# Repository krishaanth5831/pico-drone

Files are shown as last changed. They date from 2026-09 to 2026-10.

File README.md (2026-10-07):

# pico-drone

A coreless quadcopter flight controller built on a **Raspberry Pi Pico 2 W**,
written in MicroPython.

Sensor drivers, control maths, and a component-by-component bench test suite —
with a hardware disarm line that a software bug cannot override.

> **Status: bench development.** This does not fly yet. There is no control link
> on the airframe, so `main.py` deliberately stops at sensor bring-up and never
> arms the motors. See [`docs/roadmap.md`](docs/roadmap.md).

> **Before running anything: `config.py`, `drivers/` and `flight/` must be
> copied onto the Pico's own filesystem first.** Opening a script in Thonny and
> pressing Run does not upload anything — without this step every script fails
> with `ImportError: no module named 'config'`. Run `./tools/upload.sh`, or see
> [step 2 below](#2-put-the-library-on-the-board) for the Thonny method.

## Hardware

| Part | Role |
|---|---|
| Raspberry Pi Pico 2 W | Flight controller (RP2350, dual-core 150 MHz) |
| 2× DRV8833 | Dual H-bridge motor drivers, two motors each |
| 4× coreless motors | Propulsion (8520 recommended — see [`docs/power.md`](docs/power.md)) |
| GY-521 (MPU6050) | 3-axis gyro + accelerometer |
| HMC5883L | 3-axis magnetometer, yaw reference |
| GY-GPS6MV2 (NEO-6M) | GPS position |
| 1S LiPo | Power |

Full wiring: [`docs/pinout.md`](docs/pinout.md).

## Layout

```
src/
  config.py            single source of truth for every pin and constant
  main.py              entry point - sensor bring-up, motors stay disarmed
  drivers/
    motors.py          DRV8833 bank with hardware arm/disarm
    heartbeat.py       onboard-LED liveness pulse, soft-timer driven
    mpu6050.py         GY-521 gyro + accelerometer
    hmc5883l.py        magnetometer, auto-detects the QMC5883L clone
    gps.py             NEO-6M NMEA parser
  flight/
    fusion.py          complementary filter -> roll and pitch
    pid.py             rate controller, anti-windup, no derivative kick
    mixer.py           X-quad motor mixing with desaturation

testing/               per-component bench procedures + scripts
docs/                  pinout, power/thrust/weight, roadmap
hardware/              KiCad schematic + wiring diagram
  frame/               3D-printed airframe: STLs + Onshape FeatureScript source
tests/                 CPython tests against a mocked hardware layer
tools/                 repo convention checks run in CI
```

## Getting started

### 1. Flash MicroPython

Grab the Pico 2 W UF2 from
[micropython.org](https://micropython.org/download/RPI_PICO2_W/), hold
**BOOTSEL** while plugging in, and copy the file to the `RP2350` drive that
appears. Full walkthrough in [`testing/01_pico_2w/`](testing/01_pico_2w/README.md).

### 2. Put the library on the board

The bench scripts import `config`, `drivers` and `flight`, and those imports
resolve against the **Pico's** filesystem — not your computer's:

```bash
pip install mpremote
./tools/upload.sh          # --list to check, --clean to wipe first
```

Or in Thonny: `View → Files`, select `config.py`, `drivers` and `flight`,
right-click → **Upload to /**. Re-upload after any change under `src/`.

`main.py` is deliberately excluded. MicroPython auto-runs it on every boot *and
every soft-reboot* — which is what Thonny's Run button always does first — so a
`main.py` on the board hijacks every test run before your script executes. If
you see the shell print `MPY: soft reboot` repeatedly with none of your test's
own output, this is why: run `./tools/upload.sh` again, which removes it.

### 3. Work through the bench tests

Do these **in order** — each assumes the previous one passes.

| # | Component | Motors spin? |
|---|---|---|
| [01](testing/01_pico_2w/README.md) | Pico 2 W bring-up | no |
| [02](testing/02_drv8833/README.md) | DRV8833 driver, no motor attached | no |
| [03](testing/03_coreless_motor/README.md) | Motor mapping and direction | **yes** |
| [04](testing/04_gy521_imu/README.md) | IMU | no |
| [05](testing/05_hmc5883l_compass/README.md) | Compass | no |
| [06](testing/06_gy_gps6mv2/README.md) | GPS | no |
| [07](testing/07_lipo_power/README.md) | Power system, brownout hunt | **yes** |

Index and safety notes: [`testing/README.md`](testing/README.md).

### 4. Run it

**Do this separately from the bench tests above, and remove it again afterwards.**
`main.py` auto-runs on every boot and soft-reboot, so leaving it on the board
hijacks every test run in step 3 - if you go back to bench testing after this,
delete it first (`./tools/upload.sh` does this for you automatically).

```bash
mpremote fs cp src/main.py :
```

Then reset the board. You get live attitude, heading and GPS status streamed to
the REPL, with the motors held hardware-disarmed throughout.

## Safety model

**`GP15` (physical pin 20) drives `SLP` on both DRV8833s.** Held low, the driver
outputs go high-impedance and the motors are dead no matter what the PWM
registers contain. This is a hardware disarm, not a software convention.

Enforced throughout:

- `MotorBank` drives `SLP` low **before** any PWM channel is constructed, so no
  stale duty can reach a motor during startup.
- Using it as a context manager disarms on every exit path, exceptions included.
- Keep that pattern in any new motor-driving code: a `finally` block or
  `with MotorBank()`, no exceptions.
- `MAX_DUTY` is capped at 0.70 — two DRV8833s thermally shut down at sustained
  full throttle — and `tests/test_config.py` fails if it is raised.
- Nothing in this repo arms motors at power-on.

**Every bench procedure assumes props are off.**

### LED heartbeat

Every script pulses the onboard LED for as long as it runs — a long on, short off
that reads as a glow. Pulsing means the board is powered and its scheduler is
running; **stopping and restarting means it reset**, which on this airframe means
a brownout. It runs on a soft timer, so it survives blocking calls, and
Keep that pattern in anything new: start it, stop it, no orphaned timers.

It does not prove the main loop is progressing — a soft timer keeps firing even
if the code above it hangs. It catches reset and power loss, which is the failure
this hardware actually has.

## Firmware

[`firmware/`](firmware/README.md) is the integrated flight controller — sensor
fusion, cascaded PID, motor mixing, and the arm/disarm safety logic, built on
the drivers and control maths in `src/`. It self-levels and holds a heading; it
does not hold altitude or position, since nothing on this airframe measures
either. Read `firmware/README.md` in full before running it — it explains the
safety model and the manual tuning procedure, both of which matter more than
usual given there is still no control link or physical kill switch.

## Development

```bash
python3 -m venv .venv
./.venv/bin/pip install pytest ruff

./.venv/bin/python -m pytest        # 80 tests, no hardware needed
./.venv/bin/ruff check .
```

`tests/mocks/machine.py` fakes MicroPython's hardware layer — `Pin` records its
levels, `PWM` its duty, `I2C` serves bytes from a register dict — so the same
code the board runs can be exercised on a computer with no board attached.

> On a machine with ROS installed, prefix pytest with
> `env -u PYTHONPATH PYTEST_DISABLE_PLUGIN_AUTOLOAD=1` — ROS's `launch_testing`
> plugin auto-loads and crashes.

## License

[MIT](LICENSE)

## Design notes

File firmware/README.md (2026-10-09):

# Firmware — attitude-hold flight controller

This is the integrated flight code: sensor fusion, cascaded rate/angle PID
loops, motor mixing, and the safety logic that arms and disarms the motors.
It builds entirely on the drivers and control maths already validated in
`src/` and `testing/` — nothing here is new hardware code, only the loop that
ties it together.

## Wiring — every component, in one place

This mirrors [`docs/pinout.md`](../docs/pinout.md) and the per-component
tables in `testing/`, gathered here so the full airframe wiring is on one
page once you're past bench-testing individual parts and wiring the real
thing. `src/config.py` is the authoritative source if this ever drifts from
it — pins are imported from there, never hardcoded.

Hold the Pico 2 W with the **USB port at the top**. Pin 1 is the top-left
pad; numbers run down the left side (1–20), then continue up the right side
(21–40).

### Pico 2 W — onboard LED

| Signal | Pico 2 W | Physical pin | Note |
|---|---|---|---|
| Onboard LED | `Pin("LED")` | — | Behind the CYW43 WiFi chip on "W" boards — on/off only, cannot be PWM'd |

`GP23`, `GP24`, `GP25`, `GP29` are wired to the CYW43 WiFi/Bluetooth chip and
are **reserved** — never assign these. They are internal only; physical pins
29, 31, 32 and 34 are GP22, GP26, GP27 and GP28.

### DRV8833 #1 (motors 1 and 2)

| DRV8833 pin | Pico 2 W | Physical pin | Note |
|---|---|---|---|
| `VM` / `VCC` / `VMOT` | Bench: HW-131 5 V rail. Airframe: battery + direct | — | Never from the Pico |
| `GND` | Bench: HW-131 GND rail. Airframe: battery star point | — | Motor current returns here, not through the Pico |
| `SLP` / `nSLEEP` / `EEP` | GP15 | 20 | Shared with DRV #2 — hardware arm/disarm for all four motors |
| `AIN1` | GP10 | 14 | Motor 1 PWM |
| `AIN2` | GND | — | Tie low — channel A unidirectional |
| `BIN1` | GP11 | 15 | Motor 2 PWM |
| `BIN2` | GND | — | Tie low — channel B unidirectional |
| `nFAULT` *(if present)* | GP14 | 19 | Shared with DRV #2, open-drain, low = fault |
| `AOUT1`/`AOUT2` | Motor 1 leads | — | Polarity picks spin direction, not software |
| `BOUT1`/`BOUT2` | Motor 2 leads | — | Polarity picks spin direction, not software |

### DRV8833 #2 (motors 3 and 4)

Identical to #1, sharing the same `SLP`, `VM`, and `GND`:

| DRV8833 pin | Pico 2 W | Physical pin | Note |
|---|---|---|---|
| `VM` | Same as DRV #1 | — | |
| `GND` | Same as DRV #1 | — | |
| `SLP` | GP15 | 20 | Same net as DRV #1 |
| `AIN1` | GP12 | 16 | Motor 3 PWM |
| `AIN2` | GND | — | Tie low |
| `BIN1` | GP13 | 17 | Motor 4 PWM |
| `BIN2` | GND | — | Tie low |
| `nFAULT` | GP14 | 19 | Same net as DRV #1 |
| `AOUT1`/`AOUT2` | Motor 3 leads | — | |
| `BOUT1`/`BOUT2` | Motor 4 leads | — | |

### Motors — airframe positions

Standard X quad, viewed from above, nose up the page. Diagonal pairs share a
rotation direction so their yaw torques cancel in the hover.

```
      M3 (CW)          M1 (CCW)
        \                 /
         \   +--------+  /
          +--|  PICO  |-+
             |   IMU  |
          +--|        |-+
         /   +--------+  \
        /                 \
      M2 (CCW)          M4 (CW)
```

| Motor | Position | Rotation | Driver channel | PWM pin |
|---|---|---|---|---|
| M1 | front-right | CCW | DRV #1 ch A | GP10 |
| M2 | rear-left | CCW | DRV #1 ch B | GP11 |
| M3 | front-left | CW | DRV #2 ch A | GP12 |
| M4 | rear-right | CW | DRV #2 ch B | GP13 |

### GY-521 (MPU6050) — IMU, on I2C0

| GY-521 pin | Pico 2 W | Physical pin | Note |
|---|---|---|---|
| `VCC` | 3V3(OUT) | 36 | |
| `GND` | GND | 38 | |
| `SDA` | GP4 | 6 | I2C0 data, the only device on the bus |
| `SCL` | GP5 | 7 | I2C0 clock |
| `XDA`, `XCL`, `ADO`, `INT` | — | — | Leave unconnected (`ADO` floating = address `0x68`) |

Mount as close to the airframe's centre of mass as possible, and decouple
from vibration (foam tape) — bolted rigidly to the frame, prop vibration
feeds straight into the accelerometer and corrupts the attitude estimate.

### HMC5883L — compass: removed from the build

Taken out on 2026-10-09. With it attached the IMU dropped off I2C whenever the
motors ran — most likely the breadboard-rail grounding fault later found with
the GPS (see the grounding rule above), not the compass itself. It stays out:
nothing needs a heading yet, and a few cm from four motors its readings are
swamped anyway. `flight_controller.py` detects that it is missing and holds
yaw by the gyro rate loop alone, so the heading drifts slowly. See
[`testing/05_hmc5883l_compass/`](../testing/05_hmc5883l_compass/README.md) if
it comes back.

### GY-GPS6MV2 (NEO-6M) — GPS, on UART0

| GY-GPS6MV2 pin | Pico 2 W | Physical pin | Note |
|---|---|---|---|
| `VCC` | Bench: VBUS. Battery: 3V3(OUT) | 40 / 36 | VBUS is 5 V from USB into the module's own regulator — it gets a lock there and stays off the IMU's 3.3 V line |
| `GND` | GND | 3 | Directly below GP0/GP1, keeps the wire short |
| `TX` | GP1 = UART0 RX | 2 | **Crossover** — GPS transmit to Pico receive |
| `RX` | GP0 = UART0 TX | 1 | **Crossover**, only needed to reconfigure the module |

Check the board's silkscreen before wiring — these ship in `VCC RX TX GND`
and `GND TX RX VCC` header orders depending on the batch; the label is
authoritative, not the pin position. Mount with the ceramic antenna facing
up, clear view of sky, away from motors and power wiring.

### Power — bench (current setup, props off)

No battery yet. The Pico runs from the laptop's USB; the motors from an HW-131
breadboard power supply. Details and limits in
[`docs/power.md`](../docs/power.md#bench-power-hw-131-breadboard-supply).

```
USB charger (>=2 A) -> HW-131 --> rail A, jumper 5 V --> DRV #1 VM, DRV #2 VM
                              --> rail B, jumper OFF
                              --> GND rail <--+-- DRV #1 GND, DRV #2 GND
                                              +-- ONE wire to Pico GND

Laptop USB -> Pico 2 W --> 3V3 OUT (pin 36) --> GY-521 VCC
                       --> VBUS    (pin 40) --> GPS VCC
                       --> GND (38) -> GY-521 GND,  GND (3) -> GPS GND
```

**Grounding rule:** once the HW-131 is plugged in, the breadboard's power rails
are motor ground. Sensor grounds go straight to Pico GND pins (GY-521 → 38,
GPS → 3), never to a rail; exactly one wire joins Pico GND to the HW-131 GND
rail; the HW-131 runs off a wall charger, not the laptop. Break this and the IMU
drops off I2C the moment the motors spin. Full explanation and a multimeter
check in [`docs/power.md`](../docs/power.md#grounding-rule--breadboard-rails-are-motor-ground).

### Power — airframe (battery)

```
1S LiPo (+) --+-------------------> DRV #1 VM --+-- 470uF -- GND
              |                                  |
              +-------------------> DRV #2 VM --+-- 470uF -- GND
              |
              +--[ SS14 Schottky ]-> Pico VSYS (physical pin 39)

1S LiPo (-) ---- star point ----+--> DRV #1 GND
                                +--> DRV #2 GND
                                +--> Pico GND (physical pin 38)
```

| Connection | Pico 2 W | Physical pin | Note |
|---|---|---|---|
| Battery + via Schottky | VSYS | 39 | VSYS accepts 1.8–5.5 V |
| Battery − (star ground) | GND | 38 | |
| Battery + direct | — | — | To both DRV8833 `VM` pins, not to the Pico |
| *(bench only)* USB 5 V | VBUS | 40 | Alternative driver supply for bench work |

**Never connect battery + to 3V3 (pin 36)** — that regulator only supplies
~300 mA, nowhere near enough for a motor.

The 470 µF capacitors sit right at each driver's `VM`/`GND` pins as a local
energy reservoir — the battery chemistry can't respond to a millisecond
current spike, the capacitor can. The Schottky diode on VSYS stops a motor's
current surge from browning out the Pico through the shared battery rail.

### I2C addresses (I2C0, GP4/GP5)

| Device | Address |
|---|---|
| MPU6050 / GY-521 | `0x68` (`0x69` with `ADO` high) — the only device on the bus |

### Full wiring diagrams and mounting detail

Each `testing/0X_*/README.md` covers its component in more depth — soldering
gotchas, why AIN2/BIN2 are tied low, why the GPS crossover trips people up,
what a `nFAULT` low actually means. Work through those in order
(`testing/README.md` is the index) before wiring the full airframe from this
page.

## Read this before you run anything

**This is attitude stabilization, not hover.** It self-levels roll and pitch
and holds a heading, at whatever throttle `tuning.py` sets. It cannot hold
altitude or position, because nothing on this airframe measures either:

- The GPS updates at 1–5 Hz with 1–10 m accuracy — useless for noticing a 10 cm
  drop, let alone correcting one before it matters.
- There is no barometer, no sonar, no optical flow. Nothing on this bench
  measures height at all.

So this will climb, sink, and drift with wind, battery voltage sag, and
airframe asymmetry, even while perfectly level. True hover — holding a fixed
height — needs a barometer at minimum (a BMP280 is a couple of dollars and a
4-wire I2C add-on); this code leaves a clean seam for one but does not fake
having it.

**There is no control link and no physical kill switch.** The only way to stop
a misbehaving motor right now is pulling the battery. Every safety mechanism
below is a software approximation of what a real RC failsafe would do — treat
them as backups, not as a substitute for standing next to the battery
connector with your hand on it.

## Safety model

| Layer | What it does |
|---|---|
| `MotorBank()` construction | Drives `SLP` low before anything else runs — motors are hardware-disarmed the instant the script starts |
| `tuning.LIVE_MOTORS = False` (default) | The entire control loop runs and prints what it *would* do; `arm()` is never called, so nothing can spin regardless of any bug below this line |
| "Type ARM" prompt | Only reached if `LIVE_MOTORS` is `True`. Blocks until answered — no REPL attached means it blocks forever, which is the correct failure mode |
| `TILT_LIMIT_DEG` | Auto-disarms if roll or pitch exceeds this — catches a flip or a bad gain before it grinds into whatever it's mounted on |
| `RUN_SECONDS` | Auto-disarms after a fixed time no matter what — there is no way to command a stop mid-run otherwise |
| `try`/`finally` around the whole loop | Disarms on Ctrl-C, on any exception, and on the abort path — every exit disarms |

That confirmation prompt is a manual `MotorBank()` construction, not
`with MotorBank() as bank:` — the context manager's `__enter__` calls `arm()`
unconditionally, which would have spun the motors *before* the prompt was even
answered. That was a real bug caught by testing the abort path, not by reading
the code — worth remembering if you extend this file.

## Files

| File | Purpose |
|---|---|
| `flight_controller.py` | The control loop. Open it directly in Thonny and run it, same as anything in `testing/` |
| `tuning.py` | Every gain, limit, and the `LIVE_MOTORS` switch — the only file you should need to edit while tuning |
| `lift.py` | Standalone lift test: staggered spin-up, ramp, hold until Stop, with self-levelling (`LEVELLING`, level taken from how it sits at start) or bench mode (all motors equal). Gains and the `WIRING` mode live inline at the top, so Thonny edits take effect without re-uploading |
| `imu_motor_check.py` | Runs each motor on its own while hammering the IMU and counts failed reads — finds which motor (or which power/ground path) knocks the IMU off the bus |

## Setup

1. Complete `testing/01` through `testing/07` first — this assumes every
   component already works individually.
2. Run `testing/05_hmc5883l_compass/` **with the airframe fully assembled**
   and copy the printed `offset`/`scale` into `tuning.py`'s `MAG_OFFSET` /
   `MAG_SCALE`. Skipping this leaves heading-hold steering off whatever
   distortion happens to be nearby.
3. Upload the library, which now includes `tuning.py`:
   ```bash
   ./tools/upload.sh
   ```
4. Open `firmware/flight_controller.py` in Thonny and run it. `LIVE_MOTORS` is
   `False` by default — nothing can spin yet.

## Tuning procedure

Full detail and rationale is in the comments at the top of `tuning.py` — this
is the short version:

1. **Dry run, props off.** Tilt the board by hand and watch the printed mixer
   output. Confirm the *sign* of every axis before anything else: tilt right,
   the roll term should push right-side motors down and left-side up. Get a
   sign wrong here and the first live attempt flips immediately.
2. **Props on, in a restraining rig** that physically cannot leave the ground
   even at full deflection. Set `LIVE_MOTORS = True`, keep `RUN_SECONDS` short.
3. **Rate loop first**, angle gains still at zero. Raise `*_RATE_KP` from zero
   until a hand disturbance makes it oscillate at a fixed frequency, back off
   to roughly half that, then add a little `*_RATE_KD` to damp the wobble.
4. **Angle loop second**, once the rate loop is solid. Small `*_ANGLE_KP`,
   raised until it holds level without overshoot.
5. **Yaw/heading last**, using `HEADING_KP`.

If anything oscillates violently or looks like it's about to flip: set
`LIVE_MOTORS = False` and pull the battery. That's not a tuning problem to
push through — it's the signal to lower gains and re-check the rig.

## Why not autotune, why not RL

**Relay-based autotune** (forcing an oscillation and computing gains from its
period and amplitude — what Betaflight/ArduPilot's "autotune" features do
under the hood) is a legitimate, ML-free technique that could run entirely on
the Pico. It isn't built into this first version because it drives the motors
autonomously to find the oscillation, and this bench has no kill switch faster
than the battery connector. Worth adding once a physical kill switch or a real
control link exists — see `docs/roadmap.md`.

**On-device reinforcement learning** was ruled out outright. Training a
continuous-control policy from scratch typically needs 10⁴–10⁷ real
interactions; MicroPython has no autodiff and the stock firmware has no
`numpy`-equivalent (`ulab` isn't bundled by default); and every failed
training rollout on a real spinning-prop airframe is a potential crash.
Training in simulation and deploying a small pretrained policy for inference
only ("sim-to-real") is possible in principle, but needs an accurate physics
model and system identification of this specific airframe first — a
substantial project on its own, and PID will be flying reliably long before
that pipeline would even be validated.

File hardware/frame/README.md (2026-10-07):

# Frame — 3D-printed airframe

A one-piece printed quad frame sized around this build's parts, a bolt-on
GPS + compass mast, and a small tolerance coupon to print first.

| File | Part | Mass (PLA) |
|---|---|---|
| `pico_drone_frame.stl` | Frame: deck, arms, motor pods, battery bay | 8.7 g |
| `pico_drone_gps_mast.stl` | GPS + compass mast (bolts on, optional) | 2.7 g |
| `pico_drone_tolerance_coupon.stl` | Fit test: motor bores + header slots | — |
| `pico_drone_frame.fs` | Onshape FeatureScript source that generates all three | — |

The model is fully parametric in Onshape (document **Pico Drone Frame**,
private: <https://cad.onshape.com/documents/835a5cba0ddda1a520f81383>).
Double-click the *Pico Drone Frame* feature to change any dimension or
clearance, and everything regenerates. To reproduce it in another document,
paste `pico_drone_frame.fs` into a new Feature Studio and add the feature to a
Part Studio.

> **Thrust check before you print.** With the 720 motors, `docs/power.md`
> puts usable thrust at about 61 g. The fit-check model weighs the full build
> at **65.7 g without wires** (with GPS), so it will not lift. 8520 motors
> (~119 g usable) give about 1.5:1 with the GPS fitted. To refit the pods,
> set *Motor diameter* to 8.5 and re-export — the 55 mm props and every other
> dimension stay the same.

## Print

The STLs are already in print orientation: flat deck face (or platform face)
on the bed. **No supports.** Every overhang is a bridge or a 45° slope.

- PLA, 0.4 mm nozzle, 0.2 mm layers, 3 walls, any infill. Most walls are
  1.0–1.6 mm thick, so they print solid.
- Every corner is rounded and every edge has a 0.4 mm fillet (the 8 bottom
  edges of the arm webs take a smaller one), so there are no sharp edges.
  The only unrounded edges are inside the shallow 0.4 mm engraved labels.
- **Print the coupon first** (about 10 minutes):
  - **Motor rings:** 5 rings with bore allowances −0.1 / 0.0 / +0.1 /
    +0.2 / +0.3 mm, marked by 1–5 dots. Pick the ring that grips a motor
    firmly without forcing it. If that isn't the +0.1 ring (3 dots), set
    *Motor bore allowance* to its value and re-export.
  - **Header slots:** 3 slots of 3.0 / 3.4 / 3.8 mm. A 2.54 mm header strip
    should drop into the 3.4 slot freely. If it doesn't, change *Header slot
    width*.

## Layout

Nose is +X. Motor labels are engraved on the arms, and arrows on the front
two arms point forward. Rotation directions match `firmware/README.md`:

```
                  nose
      M3 (CW)              M1 (CCW)
         \                   /
          \ +--------+------+
            |        | DRV1 |
            |  Pico  |------|
            |  2 W   | IMU  |
            |        |------|
            |  USB   | DRV2 |
          / +--------+------+ \
         /     battery under    \
      M2 (CCW)              M4 (CW)
```

- The **Pico** sits in the left column with its USB port at the rear, where a
  notch in the deck leaves room for the cable. The antenna end faces the
  front edge, partly over a window in the deck.
- The **GY-521** sits in the middle of the right column, as close to the centre
  of mass as the layout allows (computed CG offset 1.5 mm, -0.2 mm). Turn it
  so the silkscreen **X arrow points to the nose**. That edge has slots on
  both sides, so either 180° orientation fits. If your board's X arrow runs
  along the short edge, tick *GY-521 silkscreen X runs along the short edge*.
- The **battery** (EEMB 852040, 20 × 40 × 8.5 mm) slides into the bay under
  the deck from the rear. It stops against the front wall and is held down by
  two 45° rails. Put a zip tie or rubber band through the rear truss windows
  so it can't slide out.

## Fitting the boards (headers stay on, pins down)

Each board's header plastic drops through a slot, so the PCB lies flat on the
deck. Its pins hang into a 10 mm wiring bay above the battery. Solder wires to
the pin tips. Dupont housings need about 18 mm: set *Wiring gap under deck* to
18 if you use them.

| Board | Held by |
|---|---|
| Pico 2 W, DRV8833 ×2 | header strips in the slots + thin double-sided tape |
| GY-521 | 1 mm foam tape (vibration isolation, per `testing/04_gy521_imu`) |
| GY-GPS6MV2 + antenna, GY-271 | foam tape on the mast platform; antenna taped on top of the NEO-6M module. Turn the GY-271 so its silkscreen X arrow points to the nose (either 180° orientation fits), and recalibrate it once it's on the airframe |
| Mast | leg tabs drop through the deck slots, 2× M2 × 6 self-tapping screws from the front and rear |
| Motors | split clamp with a 45° bottom lip; leads exit through the bottom hole |

Motor leads run along the arm webs; the two holes in each web take a zip tie.

## Tolerances

| Fit | Clearance |
|---|---|
| Board pockets | 0.3 mm per side |
| Header strip in slot (Pico, IMU, GY-271, GPS) | 3.4 mm slot for a 2.54 mm strip, 0.43 mm per side |
| DRV8833 header slots | 3.8 mm (row spacing on clone boards varies) |
| Motor bore | Ø motor + 0.1 mm with a 0.8 mm split, so the clamp grips |
| Battery bay | 0.4 mm per side |
| Mast tab in deck slot | 0.15 mm per side |

These were checked in Onshape against fit-check dummies of every part.
Minimum clearances: 0.05 mm board-to-deck (the dummies float by design),
0.26 mm at the header strip corners, 0.2 mm battery, 0.43 mm GPS header, and
more than 1 mm between the props and anything else.

## Dimensions used

- **Pico 2 W**: official datasheet. 51 × 21 × 1 mm, header rows 17.78 mm
  apart, 1.3 mm USB overhang, 14 × 9 mm antenna keep-out.
- **Clone boards**: typical published sizes. **Caliper yours** and edit the
  dialog before printing; sellers differ by 1–2 mm.

| Board | Size used |
|---|---|
| GY-521 | 21.2 × 16.4 mm |
| DRV8833 (red EEP/ULT module) | 18.5 × 16 mm |
| GY-271 | 14.8 × 13.5 mm |
| GY-GPS6MV2 | 36 × 25 mm; antenna 25 × 25 × 6.2 mm |
| 852040 battery | 42 × 20 × 8.5 mm (2 mm allowance for the protection PCB) |
| 720 motor, 55 mm props | Ø7 × 20 mm |

## Re-exporting after a change

Onshape exports in flight orientation. Either flip the part 180° about X in
the slicer, or use *lay flat* on the large deck face.

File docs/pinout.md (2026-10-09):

# Consolidated pin map

Every GPIO on the airframe, in one place. The authoritative source is
[`src/config.py`](../src/config.py) — this document mirrors it, and
Keep it that way when editing `testing/` scripts - import pins from `config.py`
rather than hardcoding a GPIO number.

## Board orientation

Hold the Pico 2 W with the **USB port at the top**. Pin 1 is the top-left pad;
numbers run down the left side (1–20), then continue up the right side (21–40).

## Signals

| Function | Device pin | Pico GPIO | Physical pin |
|---|---|---|---|
| Motor 1 PWM | DRV #1 `AIN1` | GP10 | 14 |
| Motor 2 PWM | DRV #1 `BIN1` | GP11 | 15 |
| Motor 3 PWM | DRV #2 `AIN1` | GP12 | 16 |
| Motor 4 PWM | DRV #2 `BIN1` | GP13 | 17 |
| Motor arm / kill | both DRV `SLP` | GP15 | 20 |
| Driver fault *(optional)* | both DRV `nFAULT` | GP14 | 19 |
| IMU data | GY-521 `SDA` | GP4 | 6 |
| IMU clock | GY-521 `SCL` | GP5 | 7 |
| GPS → Pico | GY-GPS6MV2 `TX` | GP1 | 2 |
| Pico → GPS | GY-GPS6MV2 `RX` | GP0 | 1 |
| — | DRV `AIN2`/`BIN2` ×4 | **tie to GND** | 3, 8, 13, 18, 23, 28, 33, 38 |

The HMC5883L compass was **removed from the build on 2026-10-09**. With it
attached the IMU dropped off I2C whenever the motors ran — most likely the same
breadboard-rail grounding fault later found with the GPS, not the compass itself.
It stays out anyway: the build doesn't need a heading yet, and a few cm from the
motors its readings are swamped. The GY-521 alone gives roll, pitch and
yaw rate; `firmware/flight_controller.py` runs without a compass (yaw rate-hold,
heading drifts slowly). Its component test in `testing/05_hmc5883l_compass/` is
kept in case it comes back on a mast.

## Power rails — bench (current setup, props off)

No battery. The Pico runs from the laptop's USB and the motors from an HW-131
(MB102-style) breadboard power supply. Full picture in
[`power.md`](power.md#bench-power-hw-131-breadboard-supply).

| Rail | Feeds | Physical pin |
|---|---|---|
| Laptop USB → Pico | the Pico itself | — |
| 3V3(OUT) | GY-521 `VCC` only | 36 |
| VBUS (5 V from USB) | GPS `VCC` (the module has its own 3.3 V regulator) | 40 |
| HW-131 rail, jumper on **5 V** | DRV #1 `VM`, DRV #2 `VM` — nothing else | — |
| HW-131 GND rail | DRV #1 `GND`, DRV #2 `GND`, one wire to Pico GND | — |
| Pico GND | GY-521 `GND` (38), GPS `GND` (3), the one wire to the HW-131 GND rail | 3, 38 |

**The breadboard's power rails are motor ground once the HW-131 is plugged in.**
Sensor grounds go straight to Pico GND pins (GY-521 → 38, GPS → 3), never to a
rail, and exactly one wire joins Pico GND to the HW-131 GND rail. Getting this
wrong knocks the IMU off I2C the moment the motors spin — see the
[grounding rule](power.md#grounding-rule--breadboard-rails-are-motor-ground).
HW-131 5 V never goes to VSYS or VBUS.

## Power rails — airframe (battery, planned)

| Rail | Feeds | Physical pin |
|---|---|---|
| 3V3(OUT) | GY-521 `VCC`, GPS `VCC` | 36 |
| VSYS ← battery via Schottky | the Pico itself | 39 |
| Battery + direct | DRV #1 `VM`, DRV #2 `VM` | — |
| GND | everything, star-grounded at the battery | 38 (also 3, 8, 13, 18, 23, 28, 33) |

## Reserved — never assign these

| GPIO | Physical pin | Used by |
|---|---|---|
| GP23 | none (internal) | CYW43 WiFi power-save |
| GP24 | none (internal) | CYW43 data |
| GP25 | none (internal) | CYW43 chip select |
| GP29 | none (internal) | CYW43 clock / VSYS sense |

These four are not broken out to the header at all. Physical pins 29, 31, 32 and
34 are GP22, GP26, GP27 and GP28, which are ordinary free GPIO.

On Pico W and Pico 2 W these are wired to the WiFi/Bluetooth chip and are not
free GPIO. That is also why the onboard LED is `Pin("LED")` rather than `Pin(25)`
and cannot be PWM'd. `tests/test_config.py` fails if any of them is assigned.

## I2C addresses

| Device | Address |
|---|---|
| MPU6050 / GY-521 | `0x68` (`0x69` with `ADO` high) |

The IMU is alone on I2C0 (GP4/GP5). A scan should return `[104]`.

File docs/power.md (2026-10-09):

# Power, thrust and weight

The three numbers that decide whether this build flies.

## Bench power (HW-131 breadboard supply)

The current setup, props off, no battery. The Pico runs from the laptop's USB
(Thonny needs it anyway); the motors run from an HW-131 (MB102-style)
breadboard supply plugged into the breadboard's rails.

```
USB charger (>=2 A) -> HW-131 --> rail A, jumper 5 V --> DRV #1 VM, DRV #2 VM
                              --> rail B, jumper OFF
                              --> GND rail <--+-- DRV #1 GND, DRV #2 GND
                                              +-- ONE wire to Pico GND

Laptop USB -> Pico 2 W --> 3V3 OUT (pin 36) --> GY-521 VCC
                       --> VBUS    (pin 40) --> GPS VCC
```

- **Feed the HW-131 from a USB charger, not the barrel jack.** On the barrel
  jack its 5 V comes through an AMS1117 that gives up around 0.7 A. On most
  boards the USB input bypasses that regulator, so the charger sets the limit.
  Not the laptop: it is already feeding the Pico.
- **The sensors stay on the Pico.** Off the HW-131 they would see every motor
  sag, and switching one supply off while the other is on back-powers through
  the I2C lines.
- **Grounding — read the rule below.** Getting it wrong takes the IMU off the
  bus as soon as the motors spin.
- **5 V on the motors is fine with props off.** `MAX_DUTY` 0.70 averages
  ~3.5 V, right at the coreless 3.7 V rating. Never raise `MAX_DUTY` on 5 V.
- **The breadboard rails carry ~1 A per contact.** Keep both DRVs close to the
  HW-131 and check for a split in the middle of long rails.
- **Kill switch:** the HW-131's power button cuts the motors instantly.
- Power-up: HW-131 on, then Pico USB. Power-down: Stop in Thonny, then HW-131 off.

### Grounding rule — breadboard rails are motor ground

**The HW-131 plugs into the breadboard's long power rails, so every one of those
rails is motor ground (and motor power).** Nothing on the sensor side may touch
them:

- **GY-521 `GND` → Pico pin 38, GPS `GND` → Pico pin 3** — straight to the Pico,
  each on its own wire. Never to a breadboard rail.
- **Exactly one wire** joins a Pico GND pin to the HW-131 GND rail. That is the
  only place the two grounds meet.
- **Feed the HW-131 from a wall charger, not a second laptop USB port.** With
  both the Pico and the HW-131 on the laptop, motor current gets a second path
  home through the laptop and the Pico's ground.
- Keep sensor wires (SDA/SCL, GPS TX/RX) away from motor leads.

**The symptom when this is wrong:** the IMU reads fine with the motors off, then
the moment they spin `lift.py` stops with `IMU stopped answering (31 failed
reads in a row)` — every read fails, not just some. The IMU alone often survives;
adding any second module (GPS, compass) wired to a rail tips it over. Seen and
fixed on 2026-10-09: moving the GPS ground off the rail onto Pico pin 3 cured it.

**Check with a multimeter:** with the motors running (`LEVELLING = False` in
`lift.py` so it keeps going), DC millivolts between Pico pin 38 and the GY-521
`GND` pin should read ~0. Tens of mV means motor current is flowing through the
sensor ground.

## Power topology (airframe, battery)

Motor current and Pico current take separate paths from the battery, meeting only
at the terminals:

```
1S LiPo (+) --+-------------------> DRV #1 VM --+-- 470uF -- GND
              |                                  |
              +-------------------> DRV #2 VM --+-- 470uF -- GND
              |
              +--[ SS14 Schottky ]-> Pico VSYS (pin 39)

1S LiPo (-) ---- star point ----+--> DRV #1 GND
                                +--> DRV #2 GND
                                +--> Pico GND (pin 38)
```

**Capacitors** absorb the millisecond current spikes the battery's chemistry
cannot. Mount them physically close to each driver's VM/GND pins.

**The Schottky** prevents USB 5 V backfeeding the LiPo when both are connected.
Without it, connect only one at a time.

**Star grounding** keeps motor return current out of the Pico's ground wire,
where it would create offset voltages that read as IMU noise.

Full brownout explanation and the test procedure:
[`testing/07_lipo_power/`](../testing/07_lipo_power/README.md).

## Driver losses

Each DRV8833 half-bridge pair has ~360 mΩ of on-resistance. At 1.5 A that drops
~0.54 V and dissipates ~0.8 W **per motor**.

| Setup | R path | Drop @1.5 A | Heat per chip | Motor sees | Thrust (8520) |
|---|---|---|---|---|---|
| **2 chips, 2 motors each** *(current build)* | 360 mΩ | 0.54 V | **1.6 W** | 3.06 V | ~101 g |
| 4 chips, 1 motor, not paralleled | 360 mΩ | 0.54 V | 0.81 W | 3.06 V | ~101 g |
| 4 chips, 1 motor, channels paralleled | 180 mΩ | 0.27 V | 0.41 W | 3.33 V | ~120 g |
| 4× SI2302 MOSFET | 50 mΩ | 0.08 V | negligible | 3.52 V | ~134 g |

*(1S pack sagging to ~3.6 V under load; coreless thrust scales roughly with V².)*

### The current build's limitation

Two chips means two motors per package at ~1.6 W. The cheap breakouts have no
heatsinking, so **sustained full throttle reaches the 150 °C thermal shutdown**
and cuts both that chip's motors without warning.

`MAX_DUTY` is capped at **0.70** in [`src/config.py`](../src/config.py) for this
reason, and `tests/test_config.py` fails if it is raised.

### Upgrade paths

**Four DRV8833s with channels paralleled** — tie `AIN1`↔`BIN1`, `AIN2`↔`BIN2`,
`AOUT1`↔`BOUT1`, `AOUT2`↔`BOUT2` on each chip, one chip per motor. Halves both
the voltage drop and the heat. Costs ~5 g, returns ~19 g of thrust. Only parallel
*within* one chip — two chips will not switch in sync.

**Four SI2302 MOSFETs** — drone props never reverse, so an H-bridge is not
needed. Recovers nearly all the loss, weighs ~1 g total, costs pennies. This is
what commercial coreless drones use.

## Weight budget

| Item | Weight |
|---|---|
| Pico 2 W (with headers) | ~10 g |
| 2× DRV8833 breakouts | ~5 g |
| GY-521 (HMC5883L removed 2026-10-09) | ~2 g |
| GY-GPS6MV2 | ~14 g |
| 1S 600 mAh LiPo | ~15 g |
| 4 motors + props | ~22 g |
| Frame, wire, connectors | ~25 g |
| **Total with GPS** | **~94 g** |
| **Total without GPS** | **~80 g** |

## Thrust-to-weight

You want **2:1 minimum** for controllable flight. Below ~1.5:1 the aircraft
cannot accelerate upward fast enough to correct a disturbance — it wallows and
eventually falls out of the sky regardless of PID tuning.

| Motor | Thrust each | Total | After driver loss | T:W with GPS | T:W without |
|---|---|---|---|---|---|
| 720 (7 mm) | ~18 g | 72 g | ~61 g | 0.65 — will not lift | 0.76 — will not lift |
| 8520 (8.5 mm) | ~35 g | 140 g | ~119 g | 1.27 — marginal | **1.49 — flyable** |

**Build v1 without the GPS.** It is 15% of all-up weight, and it is useless until
the stabilisation loop works anyway. It bolts on later in minutes.

With 8520 motors and no GPS you are at roughly 1.5:1 — enough to develop and tune
the control loop. Swapping to MOSFETs later takes it to ~1.76:1.

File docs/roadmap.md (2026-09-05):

# Roadmap

What exists, and what is still needed before this flies.

## Done

- [x] Pin map single-sourced in [`src/config.py`](../src/config.py)
- [x] Motor driver with hardware arm/disarm ([`src/drivers/motors.py`](../src/drivers/motors.py))
- [x] MPU6050, HMC5883L/QMC5883L and NEO-6M drivers
- [x] Complementary filter, PID, and X-quad mixer
- [x] Per-component bench procedures under [`testing/`](../testing/README.md)
- [x] LED heartbeat failsafe on every bench script
- [x] Attitude-hold flight controller (`firmware/`) — self-levels and holds
      heading, manually tuned; no altitude/position hold (no sensor for it)

## Next — in order

### 1. Sensor loop timing
Measure the actual achievable loop rate on the RP2350 under MicroPython. The rate
loop wants 500 Hz minimum. If MicroPython cannot hold that, the hot path moves to
`@micropython.viper` or the whole thing moves to the C/C++ SDK.

### 2. A physical kill switch

`firmware/` runs with no way to stop a misbehaving motor faster than pulling
the battery. A GPIO-wired push-button cutting `SLP` directly, independent of
whatever the main loop is doing, is cheap and should happen before any
autotune routine or untethered test.

### 3. Control link
**Nothing currently commands the aircraft.** Options:

| Option | Latency | Range | Extra parts |
|---|---|---|---|
| Pico 2 W WiFi + phone app over UDP | 50–100 ms | ~30 m | none |
| nRF24L01+ on SPI, second Pico as transmitter | ~10 ms | good | ~£2 |
| ExpressLRS receiver on UART | ~5 ms | excellent | ~£15 + transmitter |

The nRF24L01+ is the usual answer for a build like this.

### 4. Slew-limit motor output
`firmware/flight_controller.py` has the rate and angle loops implemented and
tuning-capable, but motor commands aren't slew-limited between iterations yet —
only the throttle ramp at startup is. A cascaded PID can still command a step
change in individual motor output on a bad transient; rate-limiting the mixer's
output the same way `drivers/motors.ramp()` does for throttle would catch that.

### 5. Failsafe
Link loss must cut throttle, not hold it. This is unreachable until the control
link (#3) exists — right now, arming still requires an explicit "type ARM"
confirmation at the REPL, and nothing keeps running unattended past
`RUN_SECONDS`, but there is no *link* to lose yet.

### 6. GPS modes
Position hold and return-to-home. Needs the magnetometer calibrated on the
assembled airframe — without a heading reference the controller knows where it is
but not which way it faces.

## Known constraints

- Two DRV8833s thermally shut down at sustained full throttle — see
  [`docs/power.md`](power.md)
- Thrust-to-weight is marginal with the GPS fitted; build v1 without it
- MicroPython is likely too slow for the final rate loop

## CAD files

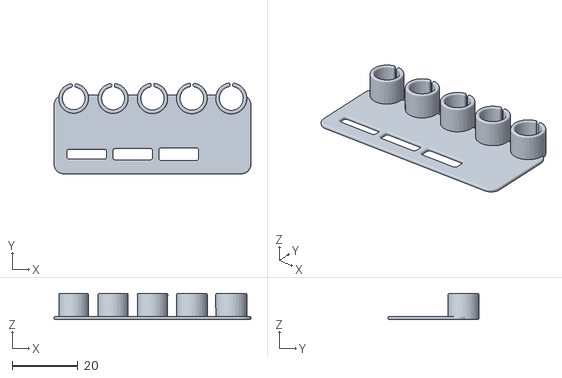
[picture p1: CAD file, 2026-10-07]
hardware/frame/pico_drone_tolerance_coupon.stl
60.0 x 27.7 x 8.00

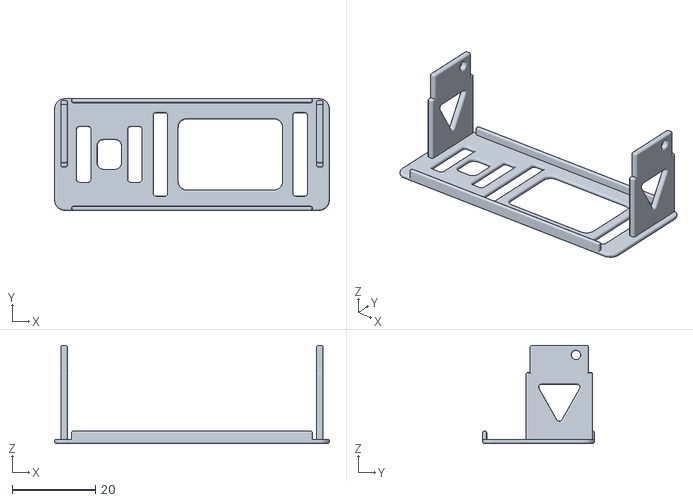
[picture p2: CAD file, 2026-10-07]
hardware/frame/pico_drone_gps_mast.stl
65.9 x 26.8 x 23.5

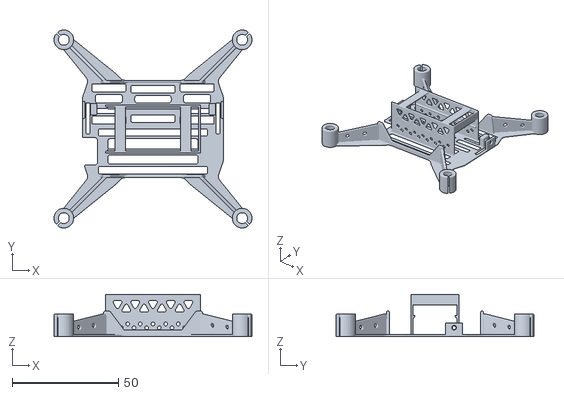
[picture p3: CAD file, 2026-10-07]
hardware/frame/pico_drone_frame.stl
93.3 x 93.3 x 19.9

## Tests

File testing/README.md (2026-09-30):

# Component bench tests

Each folder isolates **one component**, so a fault is found in the part that
causes it rather than in the assembled aircraft. Each contains a `README.md` with
a wiring table in physical pin numbers and a runnable script.

**Work through them in order.** Each assumes the previous ones pass.

| # | Component | What it proves | Motors spin? |
|---|---|---|---|
| [01](01_pico_2w/README.md) | Raspberry Pi Pico 2 W | MicroPython runs, serial works, LED blinks | no |
| [02](02_drv8833/README.md) | DRV8833 drivers | Both boards wake, all four outputs swing — measured, no motor | no |
| [03](03_coreless_motor/README.md) | Coreless motors | Each motor spins, mapping and direction correct | **yes** |
| [04](04_gy521_imu/README.md) | GY-521 / MPU6050 | Gyro + accel read, attitude tracks tilt | no |
| [05](05_hmc5883l_compass/README.md) | HMC5883L compass | Heading sweeps 0–360 correctly | no |
| [06](06_gy_gps6mv2/README.md) | GY-GPS6MV2 GPS | NMEA arrives, fix acquired outdoors | no |
| [07](07_lipo_power/README.md) | 1S LiPo power | No brownout under full four-motor load | **yes** |
| [08](08_full_stack_dry_run/README.md) | Everything together | Whole control loop closes at rate, signs correct | no |

## Before running anything that spins

- **Props off.** Every one of these procedures assumes it.
- Motors physically restrained — taped down or in a frame.
- Nothing loose on the bench near a motor.

## Running a script

### Step 0 — put the library on the board

Every script except [01](01_pico_2w/README.md) imports `config`, `drivers` and
`flight`. **Those imports resolve against the Pico's filesystem, not your
computer's.** Opening a file in an editor and pressing Run does not upload
anything, so without this step you get:

```
ImportError: no module named 'config'
```

- **Thonny** — `View → Files`. In the top (computer) pane select `config.py`,
  `drivers` and `flight`, right-click → **Upload to /**.
- **Terminal** — `./tools/upload.sh`, which needs `pip install mpremote`.
  `--list` shows what is currently on the board, `--clean` wipes it first.

Re-upload after any change under `src/`. The board keeps its own copy; editing
the file on your computer does not update it.

**`main.py` is deliberately never uploaded by this script.** MicroPython
auto-runs a file named `main.py` on every boot *and every soft-reboot* — and
Thonny's Run button always soft-reboots the board first. If `main.py` were on
the board, every test run would re-enter it instead of your script before your
script ever got a chance to execute. Its sensor bring-up blocks forever in two
places, so the symptom is total silence: the shell just prints

```
MPY: soft reboot
```

repeatedly, with none of your test's output ever appearing. `upload.sh` actively
removes `main.py` from the board if it finds one there, for exactly this reason.

### Step 1 — run it

Open the script in Thonny with the interpreter set to **MicroPython (Raspberry Pi
Pico)** and press Run.

[01](01_pico_2w/README.md) needs no upload at all — it is deliberately
self-contained so you can check the board before anything else exists on it.

## The LED heartbeat

**Every script here pulses the onboard LED for as long as it runs** — a long on,
short off that reads as a steady glow but visibly beats. It is a failsafe you can
watch without looking at the shell.

| LED | Meaning |
|---|---|
| Pulsing | The board is powered and its scheduler is running |
| Went dark | The script ended normally, or the board lost power |
| **Stopped and restarted** | The board **reset** — on this airframe that means a brownout ([07](07_lipo_power/README.md)) |
| Fast even blink | `main.py` only: a sensor failed to initialise |

It runs on a soft timer, so it keeps beating through blocking calls — the
six-second measurement pauses in [02](02_drv8833/README.md), the minutes of
waiting for a GPS fix in [06](06_gy_gps6mv2/README.md).

**What it does not prove:** that your main loop is progressing. A soft timer
fires from the scheduler and carries on even if the code above it is stuck. This
detects reset and power loss — which is what a coreless quad actually suffers
from — not a hang.

[01](01_pico_2w/README.md) is the one exception to the shared implementation: it
runs before anything has been uploaded to the board, so it carries its own copy
rather than importing `drivers/heartbeat.py`. Every other script imports the real
one.

## Safety model

`GP15` (physical pin 20) drives `SLP` on both DRV8833s. Held low, the driver
outputs go high-impedance and the motors are dead regardless of what the PWM
registers contain — a hardware disarm that a software bug cannot override.

Every script here pulls it low at start and in a `finally` block.
Every script here follows that pattern - keep it that way in anything new.

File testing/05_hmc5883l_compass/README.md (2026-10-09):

# 05 — HMC5883L magnetometer

> **Not in the current build.** The compass was removed on 2026-10-09. With it
> attached the IMU dropped off I2C whenever the motors ran — most likely a
> grounding fault (sensor ground on a breadboard rail that carried motor
> current, see [`docs/power.md`](../../docs/power.md#grounding-rule--breadboard-rails-are-motor-ground)),
> not the compass itself. The flight controller runs without it. This test stays for if it comes back,
> ideally on its own bus and up a mast away from the motors.

Supplies the absolute yaw reference the MPU6050 cannot. Without it, heading
drifts slowly over a flight. You do not need it to fly manually — you do need it
for GPS position hold or return-to-home, because otherwise the controller knows
*where* it is but not *which way it is facing*.

## HMC5883L or QMC5883L?

Two different chips ship under the same silkscreen. The driver detects which one
you have, but it helps to know:

| | HMC5883L (Honeywell) | QMC5883L (QST clone) |
|---|---|---|
| I2C address | `0x1E` | `0x0D` |
| ID registers | spell `H43` | none |
| Data order | X, **Z**, Y | X, Y, Z |

The register data order is a genuine trap: reading an HMC5883L as X, Y, Z gives a
compass that looks entirely plausible and is wrong by 90°.

## Wiring — shares I2C0 with the IMU

| HMC5883L pin | Pico 2 W | Physical pin | Note |
|---|---|---|---|
| `VCC` | 3V3(OUT) | **36** | |
| `GND` | GND | **38** | |
| `SDA` | GP4 | **6** | Same bus as the GY-521 |
| `SCL` | GP5 | **7** | Same bus as the GY-521 |
| `DRDY` | — | — | Leave unconnected |

No address conflict: the IMU answers at `0x68`, this at `0x1E` or `0x0D`. Both
modules connect to the same two Pico pins — wire them in parallel.

## Mounting — this one matters more than the others

A magnetometer measures fields in the microtesla range. Earth's field is about
50 µT; the tens of amps flowing through your power leads produce fields far
stronger than that at close range.

- Mount it **as far from motors and battery wiring as physically possible**. On
  small builds it usually shares a mast with the GPS.
- Keep it away from anything ferrous, and from the magnets in the motors.
- **Calibrate with the aircraft fully assembled and the battery connected.** The
  distortion you are cancelling comes from the airframe itself, so a calibration
  done on a bare bench is worthless once the module is bolted down.

## Upload the library first

This script imports `config`, `drivers` and `flight`. **Those imports resolve
against the Pico's filesystem, not your computer's** — opening the file in an
editor is not enough. Without this step you get:

```
ImportError: no module named 'config'
```

Upload once, and it stays there until you overwrite it:

- **Thonny** — `View → Files` so both panes show. In the top (computer) pane
  select `config.py`, `drivers` and `flight`, right-click → **Upload to /**.
- **Terminal** — `./tools/upload.sh` (needs `pip install mpremote`).

Verify with `./tools/upload.sh --list`, or just look at the bottom pane in
Thonny — you should see `config.py`, `drivers/` and `flight/` at the root.

Re-upload whenever you change anything under `src/`.

## Running the test

Run `test_hmc5883l_compass.py`. It detects the chip, runs a 30-second
calibration, then streams live heading.

During calibration, **rotate the board slowly through every orientation** — a
lazy figure-of-eight in all three axes — for the whole 30 seconds.

## What you should see

```
=== HMC5883L / QMC5883L test ===
LED pulses for as long as this runs

I2C devices : ['0x1e', '0x68']
detected    : HMC5883L

calibration: rotate slowly through all orientations for 30s
  ...
offset: (12.4, -8.1, 3.7)
scale:  (1.02, 0.97, 1.01)

streaming - rotate the board, ctrl-C to stop
  heading  47.2  |  x  18.3  y  -19.8  z  -41.2  |  field  49.8 uT
  heading 138.9  |  x -20.1  y  -17.9  z  -41.0  |  field  49.6 uT
```

**Rotate the board on a level surface and watch the heading.** Checks that
matter:

- Heading sweeps smoothly through **0 → 360** as you turn it a full circle, with
  no jumps.
- Turning **clockwise** makes the heading **increase**.
- Point it north and compare against a phone compass — within ~10° is fine.
- `field` magnitude stays roughly **25–65 µT** and barely changes as you rotate.
  A magnitude that swings wildly means calibration failed or something magnetic
  is too close.

**The onboard LED pulses throughout.** If it stops and restarts, the board reset — see [07](../07_lipo_power/README.md).

## If it fails

| Symptom | Cause |
|---|---|
| Only `MPY: soft reboot` printed, twice, nothing else | `main.py` is on the board and is hijacking every soft-reboot before your script runs. Run `./tools/upload.sh` to remove it |
| Not in the I2C scan | Wrong pins, or no power. Both this and the IMU must appear |
| `0x1E responded but ID was...` | Clone at the HMC address. Harmless, driven identically |
| Heading jumps rather than sweeping | Data register order — you likely have a QMC misdetected as HMC |
| Heading 90° off consistently | Same cause as above |
| `field` swings hugely while rotating | Uncalibrated, or hard iron too close. Re-calibrate assembled |
| Heading changes when throttle changes | Module too close to motor or battery wiring. Move it further away |

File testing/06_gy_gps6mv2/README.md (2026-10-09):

# 06 — GY-GPS6MV2 (u-blox NEO-6M) GPS

Position and ground speed. Optional for a first flight — the stabilisation loop
does not need it, and at 14 g it is a significant fraction of a coreless quad's
lift budget. See `docs/power.md` for the weight discussion.

## Wiring — UART0

| GY-GPS6MV2 pin | Pico 2 W | Physical pin | Note |
|---|---|---|---|
| `VCC` | VBUS | **40** | Bench: 5 V straight from USB into the module's MIC5205 regulator. It got a satellite lock here and not on pin 36, and keeps the GPS off the IMU's 3.3 V line. On battery (no USB) use 3V3(OUT), pin 36 |
| `GND` | GND | **3** | Straight to the Pico pin — **never a breadboard rail** when the HW-131 is on the board (the rails are motor ground; a GPS grounded there knocks the IMU off I2C when the motors spin). Pin 3 sits right below GP0/GP1 |
| `TX` | GP1 = UART0 **RX** | **2** | **Crossover** |
| `RX` | GP0 = UART0 **TX** | **1** | **Crossover**, only needed to reconfigure the module |

### Two things that catch people out

**Check your silkscreen before soldering.** These boards ship with the header in
two different orders — some `VCC RX TX GND`, others `GND TX RX VCC`. The label is
authoritative, not the position.

**TX goes to RX.** GPS transmit connects to Pico receive. Wiring TX→TX gives
total silence with no error message, and is the single most common mistake with
this module.

You can omit the GPS `RX` wire entirely if you only read the default 1 Hz stream.
Wire it anyway — you will want it to push the module to 5 Hz.

## Mounting

- **Antenna (the ceramic patch) faces up**, with a clear view of sky.
- Mount it **away from motors and power wiring**. GPS signals arrive at roughly
  −130 dBm, far below the switching noise your drivers and brushed motors
  radiate. On a small quad this means a nylon standoff lifting it a couple of
  centimetres above the frame.

## Upload the library first

This script imports `config`, `drivers` and `flight`. **Those imports resolve
against the Pico's filesystem, not your computer's** — opening the file in an
editor is not enough. Without this step you get:

```
ImportError: no module named 'config'
```

Upload once, and it stays there until you overwrite it:

- **Thonny** — `View → Files` so both panes show. In the top (computer) pane
  select `config.py`, `drivers` and `flight`, right-click → **Upload to /**.
- **Terminal** — `./tools/upload.sh` (needs `pip install mpremote`).

Verify with `./tools/upload.sh --list`, or just look at the bottom pane in
Thonny — you should see `config.py`, `drivers/` and `flight/` at the root.

Re-upload whenever you change anything under `src/`.

## Running the test

**Take it outside.** The NEO-6M will not get a fix indoors — it needs actual
sky, and there is no way around that.

Run `test_gy_gps6mv2.py`. It dumps raw NMEA first (which proves the wiring), then
switches to parsed output and waits for a fix.

## What you should see

**Stage 1 — raw NMEA, immediately, indoors or out:**

```
--- raw NMEA for 10s (proves wiring) ---
$GPRMC,,V,,,,,,,,,,N*53
$GPGGA,,,,,,0,00,99.99,,,,,,*48
$GPGSV,1,1,00*79
```

Mostly empty comma fields is **correct** with no fix yet. What matters is that
sentences arrive at all.

**Stage 2 — waiting, then a fix:**

```
--- waiting for fix (up to 300s, outdoors only) ---
waiting for fix... 0 sats visible
waiting for fix... 4 sats visible
FIX ACQUIRED after 68s
  latitude   : 51.507351
  longitude  : -0.127758
  altitude   : 21.3 m
  satellites : 7
```

**Watch the red PPS LED on the module.** It starts blinking once per second the
moment a fix is acquired — that is hardware confirmation, independent of any
code. Cold start outdoors takes 30 s to several minutes; the onboard backup
battery then makes later warm starts a few seconds.

**The onboard LED pulses throughout.** If it stops and restarts, the board reset — see [07](../07_lipo_power/README.md).

## If it fails

| Symptom | Cause |
|---|---|
| Only `MPY: soft reboot` printed, twice, nothing else | `main.py` is on the board and is hijacking every soft-reboot before your script runs. Run `./tools/upload.sh` to remove it |
| No output at all | TX/RX swapped. Swap GP0 and GP1 — this fixes it most of the time |
| Garbage bytes | Baud mismatch. Try 38400; some clones ship reconfigured |
| Sentences arrive, never a fix, indoors | Expected. Go outside |
| Sentences arrive, no fix outdoors after 10 min | Antenna face-down, or too close to the power wiring |
| `checksum errors` climbing | Noisy wiring, or baud slightly off |

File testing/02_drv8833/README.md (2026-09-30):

# 02 — DRV8833 dual H-bridge

Verifies **both driver boards** with no motor attached. You are checking that
each chip wakes up and that all four outputs actually swing, using a multimeter.
Doing this before connecting a motor means a wiring fault costs you nothing.

The script walks every channel in turn — DRV #1 `AOUT1`/`BOUT1`, then DRV #2
`AOUT1`/`BOUT1` — naming the board and pad to probe at each step. Budget about
a minute with the meter in hand.

> **No motor connected for this test.** Connect motors in `03_coreless_motor`.

## What you need

- 1× DRV8833 breakout
- Multimeter
- Pico 2 W with MicroPython flashed (see `01_pico_2w`)

## Wiring — driver #1

Orient the Pico with the **USB port at the top**. Pin 1 is the top-left pad;
numbers run down the left side (1–20) then up the right side (21–40).

| DRV8833 pin | Pico 2 W | Physical pin | Note |
|---|---|---|---|
| `VM` / `VCC` / `VMOT` | VBUS (5 V) | **40** | Bench testing only. In flight this comes from the battery |
| `GND` | GND | **38** | |
| `SLP` / `nSLEEP` / `EEP` | GP15 | **20** | Software arm/disarm. Chip is asleep when low |
| `AIN1` | GP10 | **14** | Motor 1 PWM |
| `AIN2` | GND | **33** | Tie low — makes channel A unidirectional |
| `BIN1` | GP11 | **15** | Motor 2 PWM |
| `BIN2` | GND | **33** | Tie low — makes channel B unidirectional |
| `nFAULT` *(if present)* | GP14 | **19** | Open-drain, low = over-current or thermal shutdown |
| `AOUT1`, `AOUT2` | — | — | **Leave unconnected for this test** |
| `BOUT1`, `BOUT2` | — | — | **Leave unconnected for this test** |

Driver #2 is identical except `AIN1`→GP12 (pin 16) and `BIN1`→GP13 (pin 17).
Both drivers share the same `SLP`, `VM` and `GND`.

### Why AIN2/BIN2 go to ground

The DRV8833 is an H-bridge, which can drive a motor both ways. Drone props never
reverse, so tying one input of each channel low turns it into a simple one-way
speed controller: PWM the other input and duty cycle is throttle. Rotation
direction is then set by **which way round the motor leads are soldered**, never
in software.

### The DRV8833 has only one supply pin

Whatever your board calls it — `VM`, `VCC`, `VMOT`, `VIN` — it powers both the
motor and the chip's internal logic. There is no separate logic rail.

**Never connect it to 3V3 (pin 36).** That regulator supplies ~300 mA; motors
pull several times that. Pin 36 is only for `SLP`.

## Upload the library first

This script imports `config`, `drivers` and `flight`. **Those imports resolve
against the Pico's filesystem, not your computer's** — opening the file in an
editor is not enough. Without this step you get:

```
ImportError: no module named 'config'
```

Upload once, and it stays there until you overwrite it:

- **Thonny** — `View → Files` so both panes show. In the top (computer) pane
  select `config.py`, `drivers` and `flight`, right-click → **Upload to /**.
- **Terminal** — `./tools/upload.sh` (needs `pip install mpremote`).

Verify with `./tools/upload.sh --list`, or just look at the bottom pane in
Thonny — you should see `config.py`, `drivers/` and `flight/` at the root.

Re-upload whenever you change anything under `src/`.

## Running the test

1. Wire as above, **no motors**.
2. Multimeter in DC volts, black probe on GND.
3. Run `test_drv8833.py`.
4. Follow the prompts — each names which board and which pad to probe. The
   script pauses six seconds on each, long enough to move the probe.

## What you should see

```
=== DRV8833 driver check ===
no motors should be connected
4 channels across 2 boards, about 54 s total
LED pulses for as long as this runs

SLP low  -> both drivers asleep
  measure DRV #1 AOUT1 now: expect ~0 V (high impedance)
  measure DRV #1 BOUT1 now: expect ~0 V (high impedance)
  measure DRV #2 AOUT1 now: expect ~0 V (high impedance)
  measure DRV #2 BOUT1 now: expect ~0 V (high impedance)

SLP high -> both drivers awake

-- channel 1: DRV #1 AIN1 -> AOUT1 (GP10) --
  AIN1 at 50% duty
  measure DRV #1 AOUT1 now: expect roughly 2.0-2.7 V
  back to 0%
  measure DRV #1 AOUT1 now: expect ~0 V

-- channel 2: DRV #1 BIN1 -> BOUT1 (GP11) --
  ...

nFAULT  : OK (high)
=== disarmed, LED off ===
```

A PWM output measured with a cheap multimeter reads the **average**, so 50% duty
on a 5 V rail shows somewhere around 2.0–2.7 V, not a clean 2.5 V. Anything in
that band is a pass. What matters is that it moves when the duty changes.

**The onboard LED pulses throughout.** If it stops and restarts, the board reset — see [07](../07_lipo_power/README.md).

## If it fails

| Symptom | Cause |
|---|---|
| Only `MPY: soft reboot` printed, twice, nothing else | `main.py` is on the board and is hijacking every soft-reboot before your script runs. Run `./tools/upload.sh` to remove it |
| `AOUT1` stays at 0 V always | `SLP` not reaching 3.3 V. Measure it directly — this is the most common failure and produces no error message |
| `AOUT1` sits at full 5 V | `AIN2` not tied to GND |
| `nFAULT: TRIPPED` | Over-current or thermal. With no motor attached this means an output is shorted to GND |
| Nothing on either channel of ONE board | That board's `VM` unpowered, or its GND not shared with the Pico |
| Nothing on any channel of EITHER board | `SLP` not reaching 3.3 V, or no common ground |
| `nFAULT` trips partway through | The message names the channel that was live — start there. Both boards share the line |

## Thermal reality check

This build runs **two motors per DRV8833**. Each dissipates roughly 0.8 W per
motor at 1.5 A, and the cheap breakouts have no heatsinking, so at sustained full
throttle the chip reaches its 150 °C thermal shutdown and cuts both its motors
without warning.

`MAX_DUTY` in `src/config.py` is capped at **0.70** for this reason. Do not raise
it while running two drivers.

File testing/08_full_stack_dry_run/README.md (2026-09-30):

# 08 — Full-stack dry run

Every component working together, closing the real control loop, with
**no motors attached**. Tests 01–07 each prove one part in isolation; this one
proves they coexist — sharing I2C0, UART0 and the CPU — and that the
IMU → fusion → PID → mixer → `MotorBank` chain produces sane commands fast
enough to fly on.

> **Motors must not be attached.** There is no control link on this airframe,
> so there would be no way to command a stop. The script never calls `arm()`,
> so `SLP` stays low and both DRV8833s stay asleep throughout — but wire it
> with bare driver outputs anyway.

## What you need

- The complete airframe wired as in 01–07, minus the motors
- 1S LiPo, or USB for bench power
- Nothing else — no multimeter for this one

## Wiring

This is the union of the component tests. Nothing here is new; if a section
looks unfamiliar, go back to that component's README.

### Sensors — I2C0 shared by IMU and magnetometer

| Device pin | Pico 2 W | Physical pin | Note |
|---|---|---|---|
| GY-521 `VCC`, HMC5883L `VCC` | 3V3(OUT) | **36** | |
| GY-521 `GND`, HMC5883L `GND` | GND | **38** | |
| Both `SDA` | GP4 | **6** | One bus, two addresses (0x68 and 0x1E) |
| Both `SCL` | GP5 | **7** | |

### GPS — UART0

| GY-GPS6MV2 pin | Pico 2 W | Physical pin | Note |
|---|---|---|---|
| `VCC` | 3V3(OUT) | **36** | |
| `GND` | GND | **3** | Short wire, sits below GP0/GP1 |
| `TX` | GP1 = UART0 **RX** | **2** | **Crossover** |
| `RX` | GP0 = UART0 **TX** | **1** | **Crossover** |

### Drivers — both DRV8833s, outputs bare

| DRV8833 pin | Pico 2 W | Physical pin | Note |
|---|---|---|---|
| `SLP` (both boards) | GP15 | **20** | Held **low** for this entire test |
| #1 `AIN1` | GP10 | **14** | Motor 1 — front-right |
| #1 `BIN1` | GP11 | **15** | Motor 2 — rear-left |
| #2 `AIN1` | GP12 | **16** | Motor 3 — front-left |
| #2 `BIN1` | GP13 | **17** | Motor 4 — rear-right |
| `AIN2`, `BIN2` (both) | GND | **33** | Tie low — unidirectional |
| `nFAULT` (both) | GP14 | **19** | Open-drain, shared line |
| All `OUT` pads | — | — | **Leave unconnected** |

### Power

Motor current and Pico current take **separate paths from the battery** — see
[07](../07_lipo_power/README.md) for the full treatment and the reasoning.

```
1S LiPo (+) --+-------------------> DRV #1 VM --+-- 470uF -- GND
              |                                  |
              +-------------------> DRV #2 VM --+-- 470uF -- GND
              |
              +--[ Schottky ]-----> Pico VSYS (physical pin 39)

1S LiPo (-) ---- star point ----+--> DRV #1 GND
                                +--> DRV #2 GND
                                +--> Pico GND (physical pin 38)
```

**Never connect battery + to 3V3 (pin 36).** That regulator supplies ~300 mA
and is already feeding the RP2350, the CYW43 and all three sensors.

## Running the test

1. Wire as above, **no motors on the driver outputs**.
2. Upload the library if you have not since your last `src/` change —
   `./tools/upload.sh`, or Thonny's `View → Files` → select `config.py`,
   `drivers`, `flight` → right-click → **Upload to /**.
3. Run `test_full_stack_dry_run.py`.
4. Hold the board still for the gyro calibration.
5. **Tilt the board by hand** and watch the `M1`–`M4` column.

## What you should see

```
=== full-stack dry run ===
>> MOTORS MUST NOT BE ATTACHED <<
drivers stay asleep (SLP low) for the whole run

MOTORS  disarmed (SLP low on GP15), arm() is never called
IMU     ok  (WHO_AM_I 0x68)
calibrating gyro - hold still...
  bias -0.42 0.18 0.06 deg/s
MAG     ok  (HMC5883L)
GPS     ok  (listening, fix takes 30s+ outdoors)

gains (GUESSES - not flight-tuned)
  angle  kp 0.0200  ki 0.0100  kd 0.0040
  yaw    kp 0.0030  ki 0.0000  kd 0.0000
  collective throttle 0.45, MAX_DUTY 0.70

tilt the board by hand and watch M1-M4 respond.
these are corrections: roll RIGHT -> M1,M4 up, M2,M3 down.
ctrl-C to stop.

r  +0.3 p  -0.6 | pid r+0.01 p+0.01 y+0.00 | M1 0.46 M2 0.44 M3 0.44 M4 0.46 |  480Hz hdg 214 gps 0
r +10.2 p  -1.2 | pid r-0.20 p+0.02 y-0.01 | M1 0.65 M2 0.25 M3 0.27 M4 0.67 |  478Hz hdg 231 gps 0
r +24.6 p  -1.5 | pid r-0.49 p+0.03 y-0.01 | M1 0.94 M2 0.00 M3 0.02 M4 0.95 |  477Hz hdg 238 gps 0
```

**The test passing is the asymmetry.** Level, all four motors sit at the
collective throttle. Rolled right, `M1` and `M4` (the right-hand pair) rise and
`M2`/`M3` fall — the loop pushing back toward level. Pitch forward and the rear
pair rises instead.

**The onboard LED pulses throughout.** If it stops and restarts, the board
reset — brownout, see [07](../07_lipo_power/README.md).

**Watch the Hz figure.** Anything above ~250 Hz is comfortable. If it collapses
when the GPS gets a fix, the NMEA parser is eating the loop.

## About those PID gains

**They are guesses.** They were chosen to be visibly responsive on a bench and
too soft to oscillate — they have never been near an airframe in flight.

`ANGLE_KP = 0.020` with `OUTPUT_LIMIT = 0.50` saturates at **25° of tilt** —
past that the PID output stops growing and the motor spread stops widening.
Tilting through that point and watching the numbers go static is worth doing
once. The gain is almost certainly too hot for flight, where corrections live
in the 0–5° band.

### Why this test passes `idle=0.0` and the flight code does not

`MIN_START` (0.20) exists so coreless motors never spool from a dead stop. The
mixer applies it as a hard floor **after** desaturating, so with the floor in
place the low pair pins at 0.20 from about **13°** of tilt and the differential
stops tracking your hand. Nothing spins here, so the dry run passes `idle=0.0`
and every printed number is the true PID + mixer output. Expect the low motors
to reach 0.00 near 25°; in flight they would sit at 0.20.

This test **cannot tell you a gain is wrong.** It only proves the arithmetic
runs and the signs are right. Tuning needs a tethered airframe. When you have
real numbers, move them into `src/config.py` rather than leaving them here.

## If it fails

| Symptom | Cause |
|---|---|
| `IMU FAILED` | Nothing else can proceed. See [04](../04_gy521_imu/README.md) |
| `MAG FAILED` but IMU fine | Address clash or a QMC5883L clone at 0x0D. See [05](../05_hmc5883l_compass/README.md) |
| Motors respond the **wrong way** to tilt | Accelerometer axis signs in `src/flight/fusion.py`, not the gains |
| `r`/`p` drift steadily with the board still | Gyro bias — recalibrate, holding genuinely still |
| `r`/`p` jitter violently | Loose IMU. It must be rigidly mounted, not dangling on wires |
| Hz below ~100 | Something blocking in the loop, usually GPS |
| `[DRV FAULT]` | With no motors attached, an output pad is shorted to GND |
| Board resets mid-run | Brownout. See [07](../07_lipo_power/README.md) |

## Next

This is the last test before motors go on. After this:
`03_coreless_motor` with one motor, then `07_lipo_power` for the brownout hunt,
then a tethered hover.

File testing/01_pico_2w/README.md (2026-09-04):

# 01 — Raspberry Pi Pico 2 W

Board bring-up. Nothing else is worth debugging until this passes, because every
other test depends on being able to run code and read output.

## What you need

Just the Pico 2 W and a USB cable. Nothing else connected.

## Wiring

None. This test uses only the onboard LED.

| Signal | Pico 2 W | Physical pin | Note |
|---|---|---|---|
| Onboard LED | `"LED"` | — | Behind the CYW43 WiFi chip on "W" boards, so it is **on/off only** and cannot be PWM'd |
| — | GP23, GP24, GP25, GP29 | 29, 31, 32, 34 | **Reserved.** Wired to the CYW43 chip, not free GPIO. Never assign these |

On a non-W Pico the LED is GP25 and *can* be PWM'd. `Pin("LED")` is the portable
name that works on both, which is why the code uses it.

## Flashing MicroPython

1. Download the UF2 for **Pico 2 W** from
   <https://micropython.org/download/RPI_PICO2_W/> — take the latest release.
2. Unplug the Pico.
3. Hold **BOOTSEL** down, plug the USB cable in, then release BOOTSEL.
4. A drive named `RP2350` appears. Copy the `.uf2` onto it:

   ```bash
   cp ~/Downloads/RPI_PICO2_W-*.uf2 /media/$USER/RP2350/
   sync
   ```

The board reboots the instant the copy completes and the drive vanishes. That is
success, not an error — ignore any "device removed unexpectedly" warning.

## Serial port permissions (Linux)

```bash
ls /dev/ttyACM*          # expect /dev/ttyACM0
sudo usermod -aG dialout $USER
```

Group membership is applied at login, so **log out and back in** afterwards.
To test without logging out, launch your editor through `sg`:

```bash
sg dialout -c thonny
```

A `[Errno 13] Permission denied: '/dev/ttyACM0'` in Thonny always means this,
never a wiring fault.

## Running the test

Open `test_pico_2w.py` in Thonny, set the interpreter to
**MicroPython (Raspberry Pi Pico)** in the bottom-right corner, and press Run.

## What you should see

The onboard LED blinks **three times slowly**, then **five times quickly**, and
then settles into a **steady pulse that stays lit for the rest of the run**. The
shell prints something like:

```
=== Pico 2 W bring-up ===
MicroPython : 3.4.0; MicroPython v1.24.1 on 2026-01-01 (RPi Pico 2 W with RP2350)
board       : RPi Pico 2 W with RP2350
CPU freq    : 150 MHz
free RAM    : 456384 bytes
reset cause : 1
LED         : 3 slow + 5 fast blinks - watch the board
LED         : now pulsing - stays lit while this script runs
WiFi chip   : present (CYW43 responded)

holding 8s so you can see the pulse...
=== all good ===
LED off - script ended
```

**Watch the board itself, not just the shell.** The blink pattern is proof that
code is genuinely executing on the hardware rather than the editor merely
connecting. The pulse that follows is the liveness heartbeat every other test in
this directory uses — this is your reference for what it should look like.

This script deliberately imports nothing from `src/`, because it runs before you
have uploaded any files to the board. Its heartbeat is therefore a hand-rolled
copy of `drivers/heartbeat.py`.

## If it fails

| Symptom | Cause |
|---|---|
| `Permission denied: '/dev/ttyACM0'` | dialout group — see above |
| No `/dev/ttyACM*` at all | MicroPython not flashed, or a charge-only USB cable |
| `WiFi chip: NOT detected` | You have a plain Pico 2, not a 2 W. Harmless here, but `Pin("LED")` behaves differently |
| Shell connects, LED never blinks | Board is in bootloader mode — unplug and replug without holding BOOTSEL |

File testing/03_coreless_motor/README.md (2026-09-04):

# 03 — Coreless motors

First test that actually spins something. Confirms each motor runs, identifies
which motor is which, and confirms rotation direction against the airframe
layout.

> **Props off.** A loose coreless motor with a prop fitted will fling itself
> across the bench. Props go on only after directions are confirmed.

## What you need

- Passing `02_drv8833`
- 1–4 coreless motors
- The motors physically restrained — taped down or held in a frame

## Wiring

Same as `02_drv8833`, plus the motor leads:

| Motor | Driver | Driver outputs | PWM from | Physical pin |
|---|---|---|---|---|
| **M1** front-right, CCW | DRV #1 ch A | `AOUT1`, `AOUT2` | GP10 | **14** |
| **M2** rear-left, CCW | DRV #1 ch B | `BOUT1`, `BOUT2` | GP11 | **15** |
| **M3** front-left, CW | DRV #2 ch A | `AOUT1`, `AOUT2` | GP12 | **16** |
| **M4** rear-right, CW | DRV #2 ch B | `BOUT1`, `BOUT2` | GP13 | **17** |

Motor lead polarity does not matter electrically — it only decides which way the
motor turns. That is exactly how you set rotation direction.

## Airframe layout

Standard X quad, viewed from above, nose pointing up the page. Diagonal pairs
share a rotation direction so their yaw torques cancel in the hover.

```
      M3 (CW)          M1 (CCW)
        \                 /
         \   +--------+  /
          +--|  PICO  |-+
             |   IMU  |
          +--|        |-+
         /   +--------+  \
        /                 \
      M2 (CCW)          M4 (CW)
```

## Upload the library first

This script imports `config`, `drivers` and `flight`. **Those imports resolve
against the Pico's filesystem, not your computer's** — opening the file in an
editor is not enough. Without this step you get:

```
ImportError: no module named 'config'
```

Upload once, and it stays there until you overwrite it:

- **Thonny** — `View → Files` so both panes show. In the top (computer) pane
  select `config.py`, `drivers` and `flight`, right-click → **Upload to /**.
- **Terminal** — `./tools/upload.sh` (needs `pip install mpremote`).

Verify with `./tools/upload.sh --list`, or just look at the bottom pane in
Thonny — you should see `config.py`, `drivers/` and `flight/` at the root.

Re-upload whenever you change anything under `src/`.

## Running the test

Run `test_coreless_motor.py`. It spins each motor alone, in order, with a ramp
rather than a step.

### Why it ramps instead of stepping

A coreless motor's inrush at zero rpm is several times its running current. On a
1S pack that current spike sags the rail hard enough to reset the Pico. Ramping
gives the battery time to respond. This is also why the flight code slew-limits
motor output.

## What you should see

```
=== coreless motor test ===
MAX_DUTY 0.70, props must be OFF
LED pulses for as long as this runs

motor 1 (front-right, expect CCW)
  ramping up... holding... ramping down
motor 2 (rear-left, expect CCW)
  ...
=== disarmed ===
```

**Watch the motors, one at a time.** For each one confirm:

1. It spins when its own number is printed — and no other motor moves.
2. It spins the direction the layout diagram calls for.

Mark the direction on each motor with a pen as you confirm it.

## Fixing a wrong direction

**Swap that motor's two output wires.** Never in software — the mixer in
`src/flight/mixer.py` assumes the directions in the diagram above, and changing
signs there to compensate will break yaw control in a way that is very hard to
diagnose later.

**The onboard LED pulses throughout.** If it stops and restarts, the board reset — see [07](../07_lipo_power/README.md).

## If it fails

| Symptom | Cause |
|---|---|
| Only `MPY: soft reboot` printed, twice, nothing else | `main.py` is on the board and is hijacking every soft-reboot before your script runs. Run `./tools/upload.sh` to remove it |
| Buzzes but does not turn | Duty below the motor's start threshold. Raise `MIN_START` in `src/config.py` to 0.30 |
| Wrong motor spins | Output leads swapped between channels. Check `AOUT` vs `BOUT` |
| Nothing spins at all | Go back to `02_drv8833` — this is a driver fault, not a motor fault |
| Pico resets when a motor starts | Brownout. See `07_lipo_power` |
| Motor gets hot fast | Coreless motors have no iron to sink heat. Lower `MAX_DUTY` and keep runs short |

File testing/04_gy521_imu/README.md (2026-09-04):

# 04 — GY-521 / MPU6050 IMU

The sensor the aircraft actually flies on. The gyro feeds the rate loop; the
accelerometer corrects its drift. Nothing else on the airframe can replace it —
GPS at 1 Hz and a magnetometer at 50 Hz are both orders of magnitude too slow to
keep a quad upright.

## What you need

- GY-521 breakout (MPU6050)
- 4 jumper wires

No motors involved. Safe to run on USB power alone.

## Wiring — I2C0

| GY-521 pin | Pico 2 W | Physical pin | Note |
|---|---|---|---|
| `VCC` | 3V3(OUT) | **36** | Onboard regulator accepts 3–5 V, but 3V3 is the cleaner supply |
| `GND` | GND | **38** | |
| `SDA` | GP4 | **6** | I2C0 data |
| `SCL` | GP5 | **7** | I2C0 clock |
| `XDA`, `XCL`, `ADO`, `INT` | — | — | Leave unconnected |

`ADO` floating gives address **0x68**. Pull it high for 0x69 if you ever need two
on one bus.

Most GY-521 breakouts include the 4.7 kΩ I2C pull-ups. If yours does not, add
them from SDA and SCL to 3V3.

## Mounting

Two mechanical points that matter as much as the wiring:

- **Mount it as close to the centre of mass as you can.** Off-centre, rotation
  shows up as linear acceleration and corrupts the attitude estimate.
- **Decouple it from frame vibration** — a square of double-sided foam tape is
  the standard trick. Bolted rigidly to a frame with four spinning motors, prop
  vibration feeds straight into the accelerometer and the estimate drifts badly.

Keep the wires away from motor leads. Coreless motors are brush-commutated and
throw a lot of electrical noise; corrupted I2C reads mid-flight drop your
attitude estimate.

## Upload the library first

This script imports `config`, `drivers` and `flight`. **Those imports resolve
against the Pico's filesystem, not your computer's** — opening the file in an
editor is not enough. Without this step you get:

```
ImportError: no module named 'config'
```

Upload once, and it stays there until you overwrite it:

- **Thonny** — `View → Files` so both panes show. In the top (computer) pane
  select `config.py`, `drivers` and `flight`, right-click → **Upload to /**.
- **Terminal** — `./tools/upload.sh` (needs `pip install mpremote`).

Verify with `./tools/upload.sh --list`, or just look at the bottom pane in
Thonny — you should see `config.py`, `drivers/` and `flight/` at the root.

Re-upload whenever you change anything under `src/`.

## Running the test

Put the board flat and still, then run `test_gy521_imu.py`. It scans the bus,
identifies the chip, calibrates the gyro, then streams live attitude.

**Do not move the board during calibration.** Every MPU6050 has a few deg/s of
zero offset, and integrating that uncorrected walks your heading away within
seconds.

## What you should see

```
=== GY-521 / MPU6050 test ===
LED pulses for as long as this runs

I2C devices : ['0x68']
WHO_AM_I    : 0x68 (MPU6050)
temperature : 24.8 C

calibrating gyro - hold completely still...
  bias  -1.53  0.88  0.24 deg/s

streaming - tilt the board, ctrl-C to stop
  roll   +0.3  pitch   -0.1  |  gyro   0.1  -0.2   0.0  |  accel  9.79
  roll  -28.7  pitch   +1.2  |  gyro  -2.1   0.4   0.1  |  accel  9.81
```

**Now pick the board up and tilt it.** This is the part to actually watch:

- Tilt **right** → `roll` goes positive
- Tilt **nose down** → `pitch` goes negative
- Hold any angle steady → the reading holds steady too, and does not drift away
- Lying flat → both read within a degree or two of zero
- `accel` magnitude stays near **9.81** in any orientation — that is gravity, and
  it is the check that your scaling is right

**The onboard LED pulses throughout.** If it stops and restarts, the board reset — see [07](../07_lipo_power/README.md).

## If it fails

| Symptom | Cause |
|---|---|
| Only `MPY: soft reboot` printed, twice, nothing else | `main.py` is on the board and is hijacking every soft-reboot before your script runs. Run `./tools/upload.sh` to remove it |
| `I2C devices: []` | SDA/SCL swapped, or no power. Check 3V3 at the module |
| `0x68` present, WHO_AM_I error | Clone chip. MPU6500/9250 report 0x70/0x71/0x73 and are accepted |
| Readings all zero | Chip still asleep — a failed `PWR_MGMT_1` write, usually a flaky SDA connection |
| `accel` magnitude far from 9.81 | Wrong full-scale range, or a fake chip |
| Attitude drifts steadily while still | Gyro calibration ran while the board was moving. Re-run it |
| Values jump erratically | I2C wires routed near motor leads, or missing pull-ups |

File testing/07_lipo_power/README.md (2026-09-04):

# 07 — 1S LiPo power system

Verifies the power path and hunts for brownouts. Run this **last**, once
everything else works individually, because it is the test that explains
mysterious resets in all the others.

> **Props off.** This test runs all four motors together at high throttle.

## What you need

- 1S LiPo (3.7 V nominal, 3.0–4.2 V range)
- 2× 470 µF low-ESR electrolytic capacitors
- 1× Schottky diode (SS14, 1N5819, SR240 — anything ≥1 A)
- Multimeter
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

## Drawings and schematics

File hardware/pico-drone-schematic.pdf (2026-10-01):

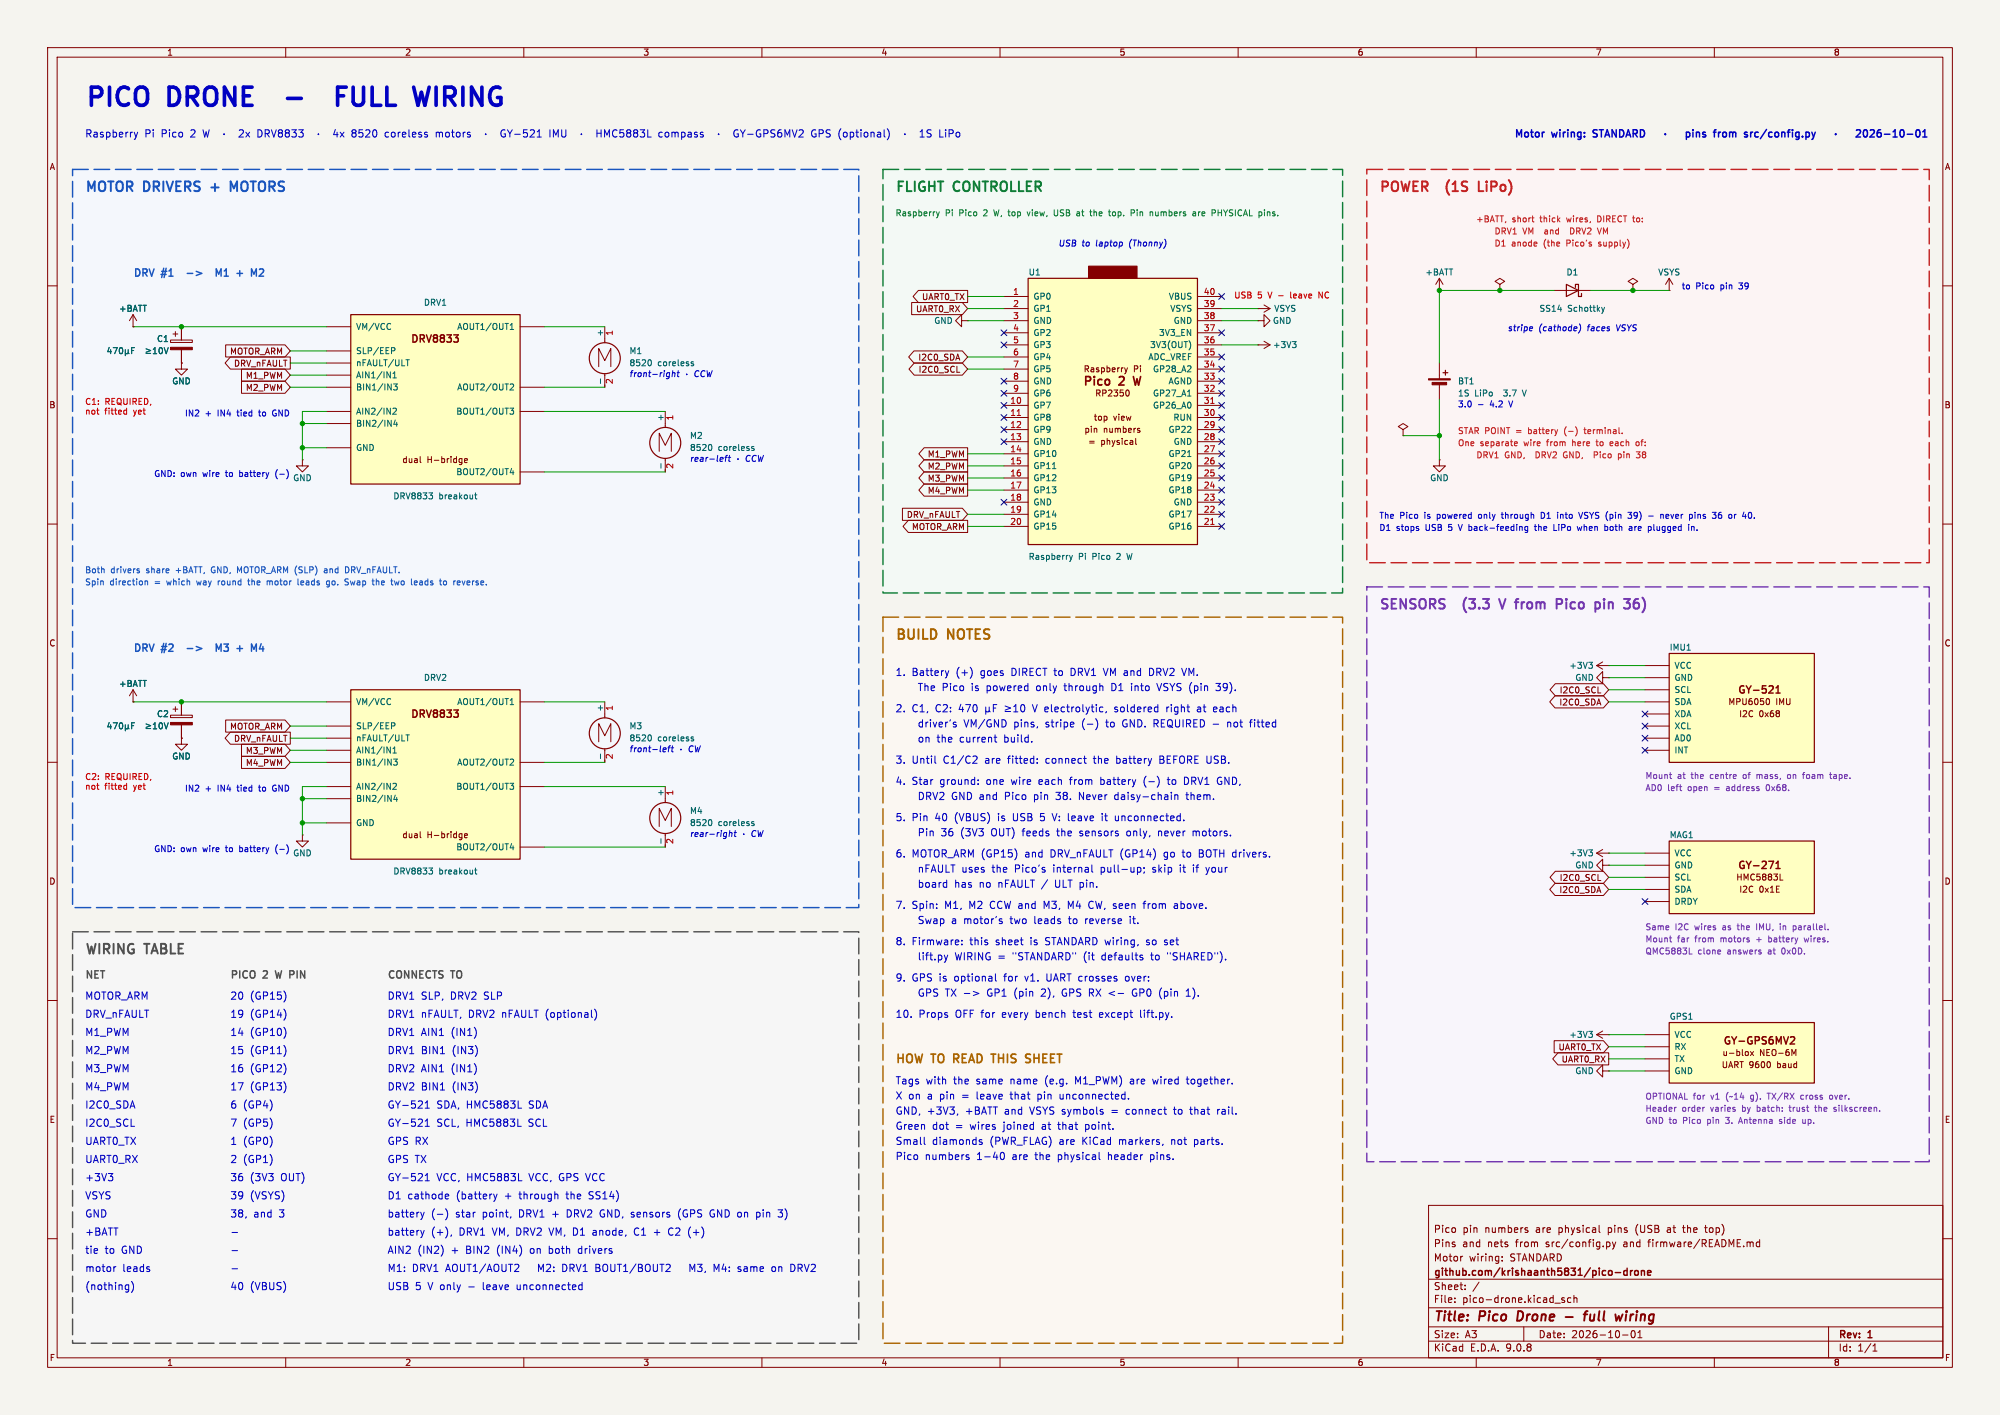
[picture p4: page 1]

Raspberry Pi Pico 2 W, top view, USB at the top. Pin numbers are PHYSICAL pins.

+BATT, short thick wires, DIRECT to:

USB to laptop (Thonny)

USB Raspberry Pi Pico 2 W

dual H-bridge VM/VCC

3. Until C1/C2 are fitted: connect the battery BEFORE USB. GND

C1: REQUIRED, not fitted yet GND: own wire to battery (-)

7. Spin: M1, M2 CCW and M3, M4 CW, seen from above.

Tags with the same name (e.g. M1_PWM) are wired together.

AIN2 (IN2) + BIN2 (IN4) on both drivers battery (+), DRV1 VM, DRV2 VM, D1 anode, C1 + C2 (+)

USB 5 V only - leave unconnected

Id: 1/1 Title: Pico Drone - full wiring

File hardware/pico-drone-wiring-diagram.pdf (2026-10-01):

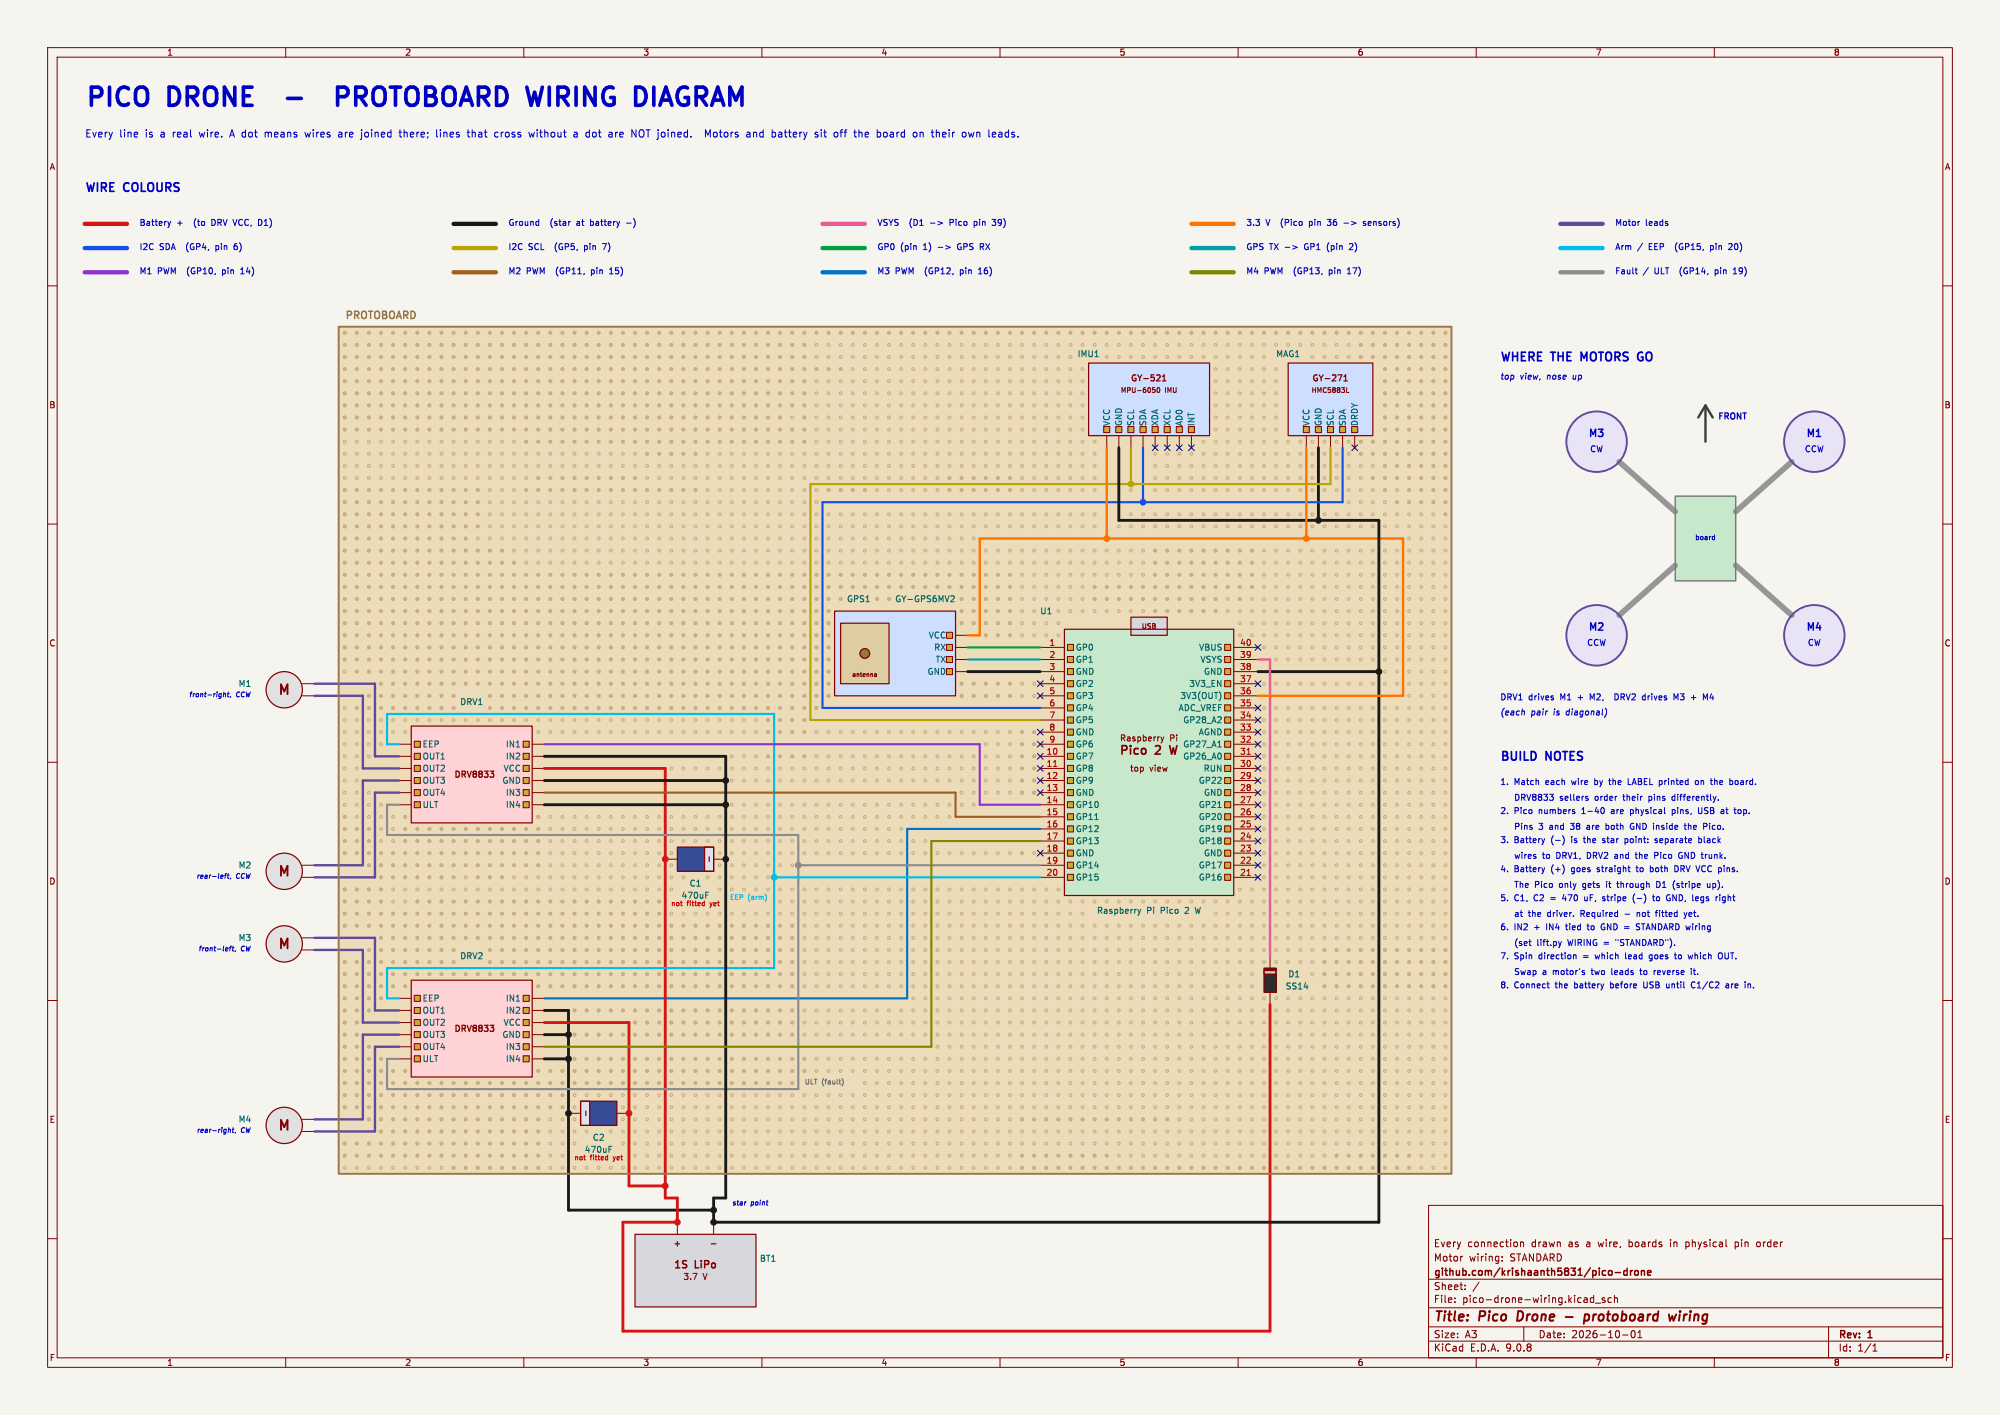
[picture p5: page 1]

Fault / ULT (GP14, pin 19) CW

GY-271 HMC5883L VCC GND SCL SDA DRDY MAG1

WHERE THE MOTORS GO

top view, nose up DRV8833 sellers order their pins differently.

6. IN2 + IN4 tied to GND = STANDARD wiring

Id: 1/1 Title: Pico Drone - protoboard wiring

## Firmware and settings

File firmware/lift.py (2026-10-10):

"""
Lift test: ramp up, try to leave the ground while self-levelling, ramp down.

Open this in Thonny and press Run. Every number you should need to touch while
tuning is in the block below, in THIS file - not in tuning.py - because
tuning.py is imported from the board's copy, so editing it in Thonny without
re-uploading silently changes nothing. Edit here, press Run, done.

At the prompt:
  ARM  -> motors spin, runs the lift profile
  DRY  -> whole control loop runs and prints, motors stay asleep (SLP low)
  else -> abort

Flight profile, all automatic (there is no control link yet):
  0 -> LIFT_THROTTLE over RAMP_UP_S, hold for HOLD_S, back to 0 over RAMP_DOWN_S.
  HOLD_S = None holds forever - press Thonny's Stop button (Ctrl-C) to end it.
Auto-disarms on tilt past TILT_LIMIT_DEG, on nFAULT, on Ctrl-C, on any error.

With SHOW_GPS on, a "gps:" line shows the lock quality and coordinates before
the ARM prompt and once a second during the run. It is display only - nothing
in the control loop uses the position, and a GPS with no data or no fix never
stops the run.

No altitude sensor exists, so "lift" here means open-loop throttle with the
attitude loop holding it level. If it doesn't leave the ground, raise
LIFT_THROTTLE. If it shoots up, lower it. Keep a hand on the battery lead.

If it stops with "IMU stopped answering" or "IMU readings frozen": the motors
are disturbing the GY-521, which is a wiring/power problem, not code. In order:
  - FIRST: no sensor ground (GY-521, GPS) on a breadboard rail. With the HW-131
    plugged in the rails are motor ground. Sensor GND straight to Pico pins,
    one wire Pico GND -> HW-131 GND (docs/power.md, "Grounding rule")
  - 10 uF (or bigger) + 100 nF capacitor across GY-521 VCC and GND, at the board
  - SDA/SCL wires short, twisted with a GND wire, routed away from motor wires
  - fully charged battery; big (470 uF) capacitor across each DRV8833 VM/GND
  - Pico powered from the battery through the Schottky, not sharing motor wires
"""

import sys
import time

sys.path.append("/")

from machine import I2C, PWM, UART, Pin  # noqa: E402

try:
    import config  # noqa: E402
    from drivers.heartbeat import Heartbeat  # noqa: E402
    from drivers.mpu6050 import MPU6050  # noqa: E402
    from flight.fusion import ComplementaryFilter  # noqa: E402
    from flight.mixer import mix  # noqa: E402
    from flight.pid import PID  # noqa: E402
except ImportError as exc:
    print("\n%s\n\nLibrary not on the Pico. Run ./tools/upload.sh, or in Thonny\n"
          "View -> Files, select config.py, drivers, flight -> 'Upload to /'.\n" % exc)
    raise SystemExit()

# The GPS is display only, so a board without drivers/gps.py still flies.
try:
    from drivers.gps import GPS  # noqa: E402
except ImportError:
    GPS = None


# =============================================================================
# EDIT HERE
# =============================================================================

# How the motors are wired to the DRV8833 outputs. Both modes use the same four
# Pico pins (GP10, GP11 on DRV #1 and GP12, GP13 on DRV #2); only the DRV side
# differs.
#
# "STANDARD"  (recommended - both motor leads on the driver, nothing to GND)
#     Each board: motor A across OUT1 + OUT2, motor B across OUT3 + OUT4.
#     IN1 -> GP10 / GP12, IN3 -> GP11 / GP13, IN2 and IN4 -> GND.
#     Each motor has its own H-bridge and gets up to config.MAX_DUTY (70%), and
#     its current returns through the driver's own GND pin instead of through
#     the breadboard ground the IMU sits on.
#
# "SHARED"  (motor A OUT1 -> GND, motor B OUT2 -> GND)
#     IN1 -> GP10 / GP12, IN2 -> GP11 / GP13.  IN2 must NOT be tied to GND.
#     Both motors share ONE H-bridge. The DRV8833 drives both outputs LOW when
#     IN1 and IN2 are both high, which brakes both motors, so the two PWM
#     pulses are interleaved: motor A fires at the start of each 50 us period,
#     motor B at the end. Each motor gets at most 50% of the time - roughly
#     half the thrust - and all motor current flows through the ground rail.
WIRING = "STANDARD"

# --- throttle profile (0.0-1.0, scaled to the wiring's duty ceiling) --------
LIFT_THROTTLE = 1.0   # raise if it won't leave the ground, lower if it rockets
RAMP_UP_S = 2.5        # slow ramp: a step to full current browns out a 1S pack
HOLD_S = None          # time at LIFT_THROTTLE; None = hold until Stop / Ctrl-C
RAMP_DOWN_S = 2.0      # descent ramp back to zero
IDLE = 0.40            # mixer floor while throttle > 0 - keep it above the
                       # weakest motor's start-up point, or that motor sits
                       # stalled, drawing current without turning

# --- bench mode ---------------------------------------------------------------
# False = all four motors get the same throttle, no self-levelling. Use it on the
# bench with props off: the board can't move, so the levelling loop just sees a
# fixed tilt (a breadboard that isn't quite flat) and keeps slowing the motors on
# the low side to the IDLE floor, where they stall. True for real flight.
LEVELLING = True

# True = "level" is however the board sits when the gyro calibrates, not true
# horizontal. A breadboard that sits a few degrees off would otherwise get a
# constant correction that pins the low-side motors to IDLE. Tilt it by hand
# from there and the motors should answer.
LEVEL_AT_START = True

# After ARM the motors start one at a time, each easing up to IDLE over this many
# seconds. Four coreless motors starting at the same instant pull a current spike
# big enough to knock the IMU off the I2C bus before the first reading.
SPINUP_S = 0.4

# --- GPS readout ----------------------------------------------------------------
# True = print GPS lock quality and coordinates (needs drivers/gps.py on the board
# and the GY-GPS6MV2 on GP0/GP1). The NEO-6M needs open sky for a fix; indoors it
# will sit at "no fix" with a few satellites, which is normal.
SHOW_GPS = True
GPS_PRINT_S = 1.0      # seconds between gps lines during the run

# --- safety -------------------------------------------------------------------
TILT_LIMIT_DEG = 35.0  # auto-disarm past this roll or pitch

# --- PID gains: guesses for a ~50-80 g coreless quad, tune by hand ------------
# Rate loop: gyro error in deg/s -> motor correction (fraction of throttle).
# 0.004 means a 100 deg/s error gives a 0.4 correction. If it wobbles fast,
# lower KP. If it feels sloppy and drifts over, raise KP. KD damps the wobble.
ROLL_RATE = (0.0040, 0.0020, 0.00006)    # (KP, KI, KD)
PITCH_RATE = (0.0040, 0.0020, 0.00006)
YAW_RATE = (0.0050, 0.0010, 0.0)

# Angle loop: tilt error in degrees -> requested rotation rate in deg/s.
# 4.0 means 10 degrees of tilt asks for 40 deg/s back towards level. Set both to
# 0.0 to tune the rate loop on its own first.
ROLL_ANGLE_KP = 4.0
PITCH_ANGLE_KP = 4.0

MAX_ANGLE_RATE_DPS = 150.0   # clamp on what the angle loop may request
RATE_I_LIMIT = 50.0          # integral clamp, deg/s * s
I_ENABLE_THROTTLE = 0.55     # integrators held at zero below this - stops them
                             # winding up while the quad still sits on the ground
TRIM_ROLL = 0.0              # constant roll correction, if it always drifts one way
TRIM_PITCH = 0.0

# =============================================================================

FULL = 65535
# Which two motors share each DRV8833, as (on IN1, on IN2/IN3). Numbers follow
# config.MOTOR_PINS and the mixer: 1 front-right, 2 rear-left, 3 front-left,
# 4 rear-right.
PAIRS = ((1, 2), (3, 4))


class Motors:
    """
    Four motors behind two DRV8833s, in either wiring mode.

    SLP goes low before any PWM exists, so there is no moment where a stale
    duty can reach a motor.
    """

    def __init__(self, wiring):
        if wiring not in ("STANDARD", "SHARED"):
            raise ValueError("WIRING must be STANDARD or SHARED")
        self.shared = wiring == "SHARED"

        self.slp = Pin(config.MOTOR_SLEEP_PIN, Pin.OUT)
        self.slp.low()

        self.fault = None
        if config.MOTOR_FAULT_PIN is not None:
            self.fault = Pin(config.MOTOR_FAULT_PIN, Pin.IN, Pin.PULL_UP)

        # Shared bridge: 50% per motor, so the two pulses can never overlap.
        # Separate bridges: the usual two-motors-per-chip thermal cap.
        self.ceiling = 0.5 if self.shared else config.MAX_DUTY

        self.pwm = {}
        for a, b in PAIRS:
            self.pwm[a] = PWM(Pin(config.MOTOR_PINS[a]), freq=config.MOTOR_PWM_FREQ,
                              duty_u16=0)
            if self.shared:
                # GP10/GP11 are PWM slice 5 channels A/B, GP12/GP13 slice 6 A/B,
                # so each pair shares one counter and stays phase-locked.
                # Channel A is high from the start of the period; channel B,
                # inverted, is high at the END of it. duty_u16=FULL inverted =
                # permanently low, i.e. off.
                self.pwm[b] = PWM(Pin(config.MOTOR_PINS[b]), freq=config.MOTOR_PWM_FREQ,
                                  duty_u16=FULL, invert=True)
            else:
                self.pwm[b] = PWM(Pin(config.MOTOR_PINS[b]), freq=config.MOTOR_PWM_FREQ,
                                  duty_u16=0)

    def _duty(self, throttle):
        throttle = 0.0 if throttle < 0.0 else (1.0 if throttle > 1.0 else throttle)
        return int(throttle * self.ceiling * FULL)

    def set_many(self, throttles):
        for a, b in PAIRS:
            self.pwm[a].duty_u16(self._duty(throttles[a]))
            if self.shared:
                self.pwm[b].duty_u16(FULL - self._duty(throttles[b]))
            else:
                self.pwm[b].duty_u16(self._duty(throttles[b]))

    def zero(self):
        self.set_many({1: 0.0, 2: 0.0, 3: 0.0, 4: 0.0})

    def arm(self):
        self.zero()
        self.slp.high()

    def disarm(self):
        self.zero()
        self.slp.low()

    def faulted(self):
        return self.fault is not None and self.fault.value() == 0


# 100 kHz instead of config's 400 kHz: slower edges survive the motor noise on
# the wires much better, and one IMU read still takes well under a millisecond.
I2C_FREQ = 100_000

# At ~300 Hz: 30 failed reads is ~0.1 s of holding the last motor outputs blind
# before giving up; 60 identical reads is ~0.2 s of a sensor that has reset.
MAX_BAD_READS = 30
MAX_FROZEN_READS = 60


def unstick_i2c(verbose=True):
    """
    Free an I2C bus the IMU is holding hostage.

    If the Pico resets mid-read (brownout when the motors spin up, Ctrl-C, a
    soft reboot from Thonny), the MPU6050 does NOT reset - it keeps its own
    power and sits halfway through sending a byte, holding SDA low forever.
    Every later read then times out with ETIMEDOUT. Clocking SCL by hand until
    it lets go of SDA, then sending a STOP, finishes that byte and frees it.
    """
    scl = Pin(config.IMU_SCL_PIN, Pin.OPEN_DRAIN, value=1)
    sda = Pin(config.IMU_SDA_PIN, Pin.IN, Pin.PULL_UP)
    if sda.value():
        return  # bus is free
    if verbose:
        print("I2C bus stuck (SDA held low), clocking it free...")
    for _ in range(18):
        scl.value(0)
        time.sleep_us(10)
        scl.value(1)
        time.sleep_us(10)
        if sda.value():
            break
    # STOP condition: SDA rises while SCL is high.
    sda = Pin(config.IMU_SDA_PIN, Pin.OPEN_DRAIN, value=0)
    time.sleep_us(10)
    scl.value(1)
    time.sleep_us(10)
    sda.value(1)
    time.sleep_us(10)


# GGA fix-quality field. The NEO-6M only ever reports 0, 1 or 6 (2 needs SBAS).
FIX_NAMES = {0: "no fix", 1: "GPS fix", 2: "DGPS fix", 6: "estimated"}


def start_gps():
    """The GPS on its UART, or None if it is switched off or not on the board."""
    if not SHOW_GPS:
        return None
    if GPS is None:
        print("gps: drivers/gps.py not on the board - upload drivers to see GPS")
        return None
    # A 1 KB receive buffer holds a full second of NMEA, so nothing is lost
    # while the loop is busy or the ARM prompt is waiting.
    uart = UART(config.GPS_UART_ID, baudrate=config.GPS_BAUD,
                tx=Pin(config.GPS_TX_PIN), rx=Pin(config.GPS_RX_PIN), rxbuf=1024)
    return GPS(uart)


def hdop_rating(hdop):
    """Horizontal dilution of precision: lower is better, under 2 is good."""
    if hdop is None:
        return "?"
    if hdop < 1.0:
        return "ideal"
    if hdop < 2.0:
        return "excellent"
    if hdop < 5.0:
        return "good"
    if hdop < 10.0:
        return "moderate"
    return "poor"


def gps_line(gps):
    """One-line GPS status: lock quality, then coordinates once there is a fix."""
    if gps.sentences_seen == 0:
        return ("gps: no data - check GPS TX -> GP%d (pin 2), and GPS VCC on "
                "VBUS (pin 40)" % config.GPS_RX_PIN)
    fix = gps.fix
    quality = FIX_NAMES.get(fix.quality, "quality %d" % fix.quality)
    if not fix.valid or fix.lat is None:
        return "gps: %s, %d sats - needs open sky" % (quality, fix.satellites)
    hdop = "%.1f" % fix.hdop if fix.hdop is not None else "?"
    alt = "%.0fm" % fix.alt_m if fix.alt_m is not None else "?"
    return ("gps: %s, %d sats, hdop %s (%s)  lat %.6f lon %.6f  alt %s"
            % (quality, fix.satellites, hdop, hdop_rating(fix.hdop),
               fix.lat, fix.lon, alt))


def throttle_at(t):
    """The flight profile. Returns None once it is over."""
    if t < RAMP_UP_S:
        return LIFT_THROTTLE * t / RAMP_UP_S
    t -= RAMP_UP_S
    # No hold time set: stay at LIFT_THROTTLE forever. Thonny's Stop button
    # sends Ctrl-C, which lands in run()'s KeyboardInterrupt handler and the
    # finally block disarms - motors cut straight to zero, no ramp down.
    if HOLD_S is None or t < HOLD_S:
        return LIFT_THROTTLE
    t -= HOLD_S
    if t < RAMP_DOWN_S:
        return LIFT_THROTTLE * (1.0 - t / RAMP_DOWN_S)
    return None


def run():
    print("\n=== pico-drone lift test ===")
    if HOLD_S is None:
        print("wiring %s, throttle %.2f, profile %.1fs up / hold until Stop (Ctrl-C)"
              % (WIRING, LIFT_THROTTLE, RAMP_UP_S))
    else:
        print("wiring %s, throttle %.2f, profile %.1fs up / %.1fs hold / %.1fs down"
              % (WIRING, LIFT_THROTTLE, RAMP_UP_S, HOLD_S, RAMP_DOWN_S))
    if not LEVELLING:
        print("LEVELLING off - bench mode, all motors get the same throttle")

    # Motors first, so SLP is low before anything that can fail or block.
    motors = Motors(WIRING)
    # Solid, not pulse: a pulsing LED runs on a soft timer, and Thonny's Stop
    # (Ctrl-C) can land inside that timer callback instead of the main loop -
    # the loop then never sees it and the motors keep spinning until a second
    # Stop. With no timer, Ctrl-C always reaches the KeyboardInterrupt below.
    heartbeat = Heartbeat("solid").start()

    try:
        # Started first so it is already collecting sentences during the gyro
        # calibration, and has something to show by the ARM prompt.
        gps = start_gps()
        unstick_i2c()
        i2c = I2C(config.IMU_I2C_ID, sda=Pin(config.IMU_SDA_PIN),
                  scl=Pin(config.IMU_SCL_PIN), freq=I2C_FREQ)
        try:
            imu = MPU6050(i2c=i2c)
        except OSError:
            print("\nIMU not answering on I2C (found: %s)." % [hex(a) for a in i2c.scan()])
            print("Unplug USB AND battery for 5 s so the IMU fully powers off, then")
            print("check the GY-521 SDA -> GP4 (pin 6) and SCL -> GP5 (pin 7) wires.")
            return
        print("IMU ok")
        print("Calibrating gyro, keep the quad flat and still...")
        imu.calibrate_gyro()

        rate = {
            "roll": PID(*ROLL_RATE, integral_limit=RATE_I_LIMIT),
            "pitch": PID(*PITCH_RATE, integral_limit=RATE_I_LIMIT),
            "yaw": PID(*YAW_RATE, integral_limit=RATE_I_LIMIT),
        }
        angle = {
            "roll": PID(ROLL_ANGLE_KP, 0.0, 0.0, output_limit=MAX_ANGLE_RATE_DPS),
            "pitch": PID(PITCH_ANGLE_KP, 0.0, 0.0, output_limit=MAX_ANGLE_RATE_DPS),
        }
        fusion = ComplementaryFilter(alpha=0.98)
        accel, gyro, _ = imu.read()
        fusion.update(accel, gyro, 0.002)
        # The first update seeds the filter straight from the accelerometer, so
        # this is the board's real resting attitude.
        level_roll = level_pitch = 0.0
        if LEVEL_AT_START:
            level_roll, level_pitch = fusion.roll_deg, fusion.pitch_deg
            print("level = roll %+.1f pitch %+.1f (as it sits now)" % (level_roll, level_pitch))

        if gps is not None:
            gps.update()
            print(gps_line(gps))

        answer = input("\nProps on, clear area. Type ARM to fly, DRY for a motors-off "
                       "run, anything else aborts: ").strip().upper()
        if answer == "ARM":
            live = True
        elif answer == "DRY":
            live = False
            print("DRY run - SLP stays low, nothing can spin.")
        else:
            print("Aborted.")
            return

        if live:
            motors.arm()
            print("ARMED")

        start = time.ticks_ms()
        last = time.ticks_us()
        last_print = start
        loops = 0
        reason = "profile complete, landed"
        bad_reads = 0      # consecutive failed IMU reads
        i2c_errors = 0     # total, shown in the printout
        frozen = 0         # consecutive bit-identical IMU readings
        prev = None
        last_gps_print = start

        try:
            if live:
                spin = {1: 0.0, 2: 0.0, 3: 0.0, 4: 0.0}
                steps = max(1, int(SPINUP_S / 0.02))
                for m in (1, 2, 3, 4):
                    for i in range(1, steps + 1):
                        spin[m] = IDLE * i / steps
                        motors.set_many(spin)
                        time.sleep_ms(20)
                print("all four spinning at IDLE %.2f" % IDLE)
                # The profile starts now, not at ARM, so the ramp isn't half
                # used up by the spin-up.
                start = time.ticks_ms()
                last = time.ticks_us()
                last_print = start
                last_gps_print = start

            while True:
                now_ms = time.ticks_ms()
                t = time.ticks_diff(now_ms, start) / 1000.0
                throttle = throttle_at(t)
                if throttle is None:
                    break

                now_us = time.ticks_us()
                dt = time.ticks_diff(now_us, last) / 1_000_000.0
                last = now_us
                loops += 1

                # Motor current spikes corrupt the odd I2C transfer. Ride out a
                # short burst of failures with the motors held where they were,
                # re-freeing the bus each time; only give up if it stays dead.
                # With LEVELLING off nothing uses the IMU to drive the motors, so
                # a dead IMU is only counted - the motors keep following the
                # profile and the i2c err column shows how bad the noise is.
                imu_ok = True
                try:
                    accel, gyro, _ = imu.read()
                    bad_reads = 0
                except OSError:
                    imu_ok = False
                    bad_reads += 1
                    i2c_errors += 1
                    if LEVELLING and bad_reads > MAX_BAD_READS:
                        reason = ("IMU stopped answering (%d failed reads in a row) - "
                                  "check no sensor GND is on a breadboard rail, "
                                  "see top of file" % bad_reads)
                        break
                    unstick_i2c(verbose=False)  # count shows in the printout
                    imu.i2c = I2C(config.IMU_I2C_ID, sda=Pin(config.IMU_SDA_PIN),
                                  scl=Pin(config.IMU_SCL_PIN), freq=I2C_FREQ)
                    if LEVELLING:
                        continue

                # A power dip resets the MPU6050 into sleep mode, where it keeps
                # answering but returns the same frozen numbers forever. A live
                # sensor is never bit-identical this many reads in a row.
                if imu_ok and (accel, gyro) == prev:
                    frozen += 1
                    if LEVELLING and frozen > MAX_FROZEN_READS:
                        reason = ("IMU readings frozen - it lost power and reset "
                                  "itself. Power/noise problem, see top of file")
                        break
                elif imu_ok:
                    frozen = 0
                prev = (accel, gyro)

                if imu_ok:
                    fusion.update(accel, gyro, dt)
                roll, pitch = fusion.roll_deg, fusion.pitch_deg

                if abs(roll) > TILT_LIMIT_DEG or abs(pitch) > TILT_LIMIT_DEG:
                    reason = "TILT LIMIT (roll %+.0f pitch %+.0f)" % (roll, pitch)
                    break

                # Still on the ground: keep the integrators empty, otherwise they
                # soak up the floor's resistance and lurch the quad on liftoff.
                if throttle < I_ENABLE_THROTTLE:
                    for pid in rate.values():
                        pid._integral = 0.0

                roll_sp = angle["roll"].update(level_roll, roll, dt)
                pitch_sp = angle["pitch"].update(level_pitch, pitch, dt)
                roll_cmd = rate["roll"].update(roll_sp, gyro[0], dt) + TRIM_ROLL
                pitch_cmd = rate["pitch"].update(pitch_sp, gyro[1], dt) + TRIM_PITCH
                yaw_cmd = rate["yaw"].update(0.0, gyro[2], dt)

                if not LEVELLING:
                    roll_cmd = pitch_cmd = yaw_cmd = 0.0

                out = mix(throttle, roll_cmd, pitch_cmd, yaw_cmd, idle=IDLE)
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

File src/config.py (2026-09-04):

"""
Single source of truth for the airframe's pin map and tuning constants.

Every module and every script under testing/ imports from here, so a wiring
change is a one-line edit in one file rather than a hunt through the tree.

Board: Raspberry Pi Pico 2 W (RP2350).

  GP23, GP24, GP25 and GP29 are wired to the CYW43 WiFi/Bluetooth chip on the
  "W" boards and are NOT free GPIO. Never assign them here.
"""

# --- Motors -----------------------------------------------------------------
# Two DRV8833s, two motors each. Each motor is driven from one channel with the
# second input of that channel tied to GND on the breakout, which makes it
# unidirectional (fast decay). Rotation direction is set by which way round the
# motor leads are soldered, never in software.
#
#   M1  DRV#1 AIN1      M3  DRV#2 AIN1
#   M2  DRV#1 BIN1      M4  DRV#2 BIN1
MOTOR_PINS = {
    1: 10,  # physical pin 14 - front-right, CCW
    2: 11,  # physical pin 15 - rear-left,   CCW
    3: 12,  # physical pin 16 - front-left,  CW
    4: 13,  # physical pin 17 - rear-right,  CW
}

# Pulled low = both DRV8833s asleep, outputs high-impedance, motors dead
# regardless of what the PWM registers hold. This is the hardware disarm.
MOTOR_SLEEP_PIN = 15  # physical pin 20 -> SLP on both drivers

# Optional: DRV8833 nFAULT is open-drain, needs a pull-up. Low = over-current
# or thermal shutdown has tripped.
MOTOR_FAULT_PIN = 14  # physical pin 19, or None if not wired

MOTOR_PWM_FREQ = 20_000  # Hz, above hearing range

# Two DRV8833s means two motors per package. Each dissipates roughly 0.8 W per
# motor at 1.5 A, and the cheap breakouts have no heatsinking, so sustained full
# throttle trips the 150 C thermal shutdown. Cap it.
MAX_DUTY = 0.70

# Below this a coreless motor buzzes without turning. Anything lower is wasted
# range at the bottom of the throttle curve.
MIN_START = 0.20

# --- IMU: GY-521 / MPU6050 (I2C0) -------------------------------------------
IMU_I2C_ID = 0
IMU_SDA_PIN = 4  # physical pin 6
IMU_SCL_PIN = 5  # physical pin 7
IMU_ADDR = 0x68  # 0x69 if AD0 is pulled high

# --- Magnetometer: HMC5883L (shares I2C0 with the IMU) ----------------------
# QMC5883L clones answer at 0x0D instead - see testing/05_hmc5883l_compass.
MAG_ADDR = 0x1E

I2C_FREQ = 400_000

# --- GPS: GY-GPS6MV2 / u-blox NEO-6M (UART0) --------------------------------
# Crossover: module TX -> Pico RX, module RX -> Pico TX.
GPS_UART_ID = 0
GPS_TX_PIN = 0  # physical pin 1 -> module RX
GPS_RX_PIN = 1  # physical pin 2 -> module TX
GPS_BAUD = 9600  # u-blox factory default

# --- Onboard LED ------------------------------------------------------------
# "LED" is the portable name. On the Pico 2 W it is behind the CYW43 chip, so it
# is on/off only and cannot be PWM'd.
LED_PIN = "LED"

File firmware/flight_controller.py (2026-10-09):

"""
Attitude-hold flight controller. NOT a full hover controller - read
firmware/README.md before running this, it explains exactly what this can and
cannot do and why.

In one sentence: this self-levels roll and pitch and holds a heading, at
whatever throttle firmware/tuning.py sets. It does not hold altitude or
position - nothing on this airframe measures either.

Safety model, in order of what actually stops the motors:

  1. MotorBank drives SLP low the instant it is constructed - before this file
     does anything else - so nothing can spin until arm() is explicitly called.
  2. tuning.LIVE_MOTORS must be True, or arm() is never called at all. Default
     is False: the whole control loop runs and prints what it WOULD do.
  3. With LIVE_MOTORS True, a "type ARM and press enter" prompt still has to be
     answered before arm() is called or the throttle ramp starts. This is a
     manual construction, not "with MotorBank() as bank" - that context manager
     arms unconditionally on entry, which would defeat the confirmation prompt
     entirely. Found by testing the abort path, not by inspection.
  4. Once armed, TILT_LIMIT_DEG and RUN_SECONDS auto-disarm on their own -
     there is no control link, so nothing else can tell this to stop.
  5. Ctrl-C, any exception, the early abort return, and a normal exit all route
     through a plain try/finally around bank.disarm(), so every path disarms.

None of this replaces a physical kill switch or a real control link with a
failsafe - both are still on the roadmap (docs/roadmap.md). Until then, keep a
hand on the battery connector.
"""

import sys
import time

sys.path.append("/")

from machine import I2C, Pin  # noqa: E402

try:
    import config  # noqa: E402
    import tuning  # noqa: E402
    from drivers import hmc5883l  # noqa: E402
    from drivers.heartbeat import Heartbeat  # noqa: E402
    from drivers.motors import MotorBank  # noqa: E402
    from drivers.mpu6050 import MPU6050  # noqa: E402
    from flight.angles import wrap_deg_error  # noqa: E402
    from flight.fusion import ComplementaryFilter  # noqa: E402
    from flight.mixer import mix  # noqa: E402
    from flight.pid import PID  # noqa: E402
except ImportError as exc:
    print(
        "\n%s\n\n"
        "The library modules are not on the Pico yet. These imports resolve\n"
        "against the BOARD's filesystem, not your computer's, so opening this\n"
        "file in an editor is not enough.\n\n"
        "Upload them once, then run this again:\n"
        "  Thonny   : View -> Files. In the top pane select config.py, drivers,\n"
        "             flight and firmware/tuning.py, right-click -> 'Upload to /'\n"
        "  Terminal : ./tools/upload.sh\n" % exc
    )
    raise SystemExit()


def build_sensors():
    """IMU and magnetometer bring-up. Raises if either is missing - there is no
    sensible degraded mode for a flight controller with a dead gyro."""
    i2c = I2C(
        config.IMU_I2C_ID,
        sda=Pin(config.IMU_SDA_PIN),
        scl=Pin(config.IMU_SCL_PIN),
        freq=config.I2C_FREQ,
    )
    found = i2c.scan()
    print("I2C devices :", [hex(a) for a in found])

    imu = MPU6050(i2c=i2c)
    print("IMU         : WHO_AM_I 0x%02X" % imu.who_am_i)
    print("calibrating gyro - hold completely still...")
    print("  bias %.2f %.2f %.2f deg/s" % imu.calibrate_gyro())

    # The compass is optional: the HMC5883L was taken out of the build on
    # 2026-10-09 (it upset the IMU on the shared bus, and a few cm from the
    # motors its readings are swamped anyway). Without it yaw is held by the
    # gyro rate loop alone - no spinning, but the heading slowly drifts.
    try:
        mag = hmc5883l.detect(i2c)
    except OSError:
        mag = None
        print("MAG         : none - yaw rate-hold only, heading will drift")
    else:
        mag.offset = tuning.MAG_OFFSET
        mag.scale = tuning.MAG_SCALE
        print("MAG         : %s (offset/scale from firmware/tuning.py)" % type(mag).__name__)

    return imu, mag


def confirm_arm():
    """The only arming gate this airframe has. Blocks until answered - if
    nothing is attached to the REPL, this blocks forever, which is the correct
    failure mode: no confirmation reachable means never armed."""
    print("\n!! LIVE_MOTORS is True - props must be on a restrained rig. !!")
    answer = input("Type ARM and press enter to spin up, anything else to abort: ")
    return answer.strip().upper() == "ARM"


def build_pids():
    """One PID per rate axis, plus two angle-loop PIDs. Yaw's angle equivalent
    is the heading-error P term computed inline in the main loop - heading is
    already an angle with nothing above it to cascade from."""
    rate = {
        "roll": PID(tuning.ROLL_RATE_KP, tuning.ROLL_RATE_KI, tuning.ROLL_RATE_KD,
                    integral_limit=tuning.RATE_INTEGRAL_LIMIT),
        "pitch": PID(tuning.PITCH_RATE_KP, tuning.PITCH_RATE_KI, tuning.PITCH_RATE_KD,
                     integral_limit=tuning.RATE_INTEGRAL_LIMIT),
        "yaw": PID(tuning.YAW_RATE_KP, tuning.YAW_RATE_KI, tuning.YAW_RATE_KD,
                   integral_limit=tuning.RATE_INTEGRAL_LIMIT),
    }
    angle = {
        "roll": PID(tuning.ROLL_ANGLE_KP, tuning.ROLL_ANGLE_KI, tuning.ROLL_ANGLE_KD,
                    output_limit=tuning.MAX_ANGLE_RATE_DPS),
        "pitch": PID(tuning.PITCH_ANGLE_KP, tuning.PITCH_ANGLE_KI, tuning.PITCH_ANGLE_KD,
                     output_limit=tuning.MAX_ANGLE_RATE_DPS),
    }
    return rate, angle


def control_step(imu, mag, fusion, rate_pid, angle_pid, heading_setpoint, dt):
    """
    One iteration of sensor read -> fusion -> cascaded PID -> mixer inputs.

    Returns (roll_deg, pitch_deg, heading, heading_error, roll_cmd, pitch_cmd,
    yaw_cmd) so the caller can both drive the mixer and print status without
    reading sensors twice.
    """
    accel, gyro, _ = imu.read()
    roll_deg, pitch_deg = fusion.roll_deg, fusion.pitch_deg
    fusion.update(accel, gyro, dt)
    gyro_x, gyro_y, gyro_z = gyro

    roll_rate_sp = angle_pid["roll"].update(0.0, roll_deg, dt)
    pitch_rate_sp = angle_pid["pitch"].update(0.0, pitch_deg, dt)

    if mag is None:
        # No compass: ask for zero yaw rotation instead of a heading.
        heading, heading_error, yaw_rate_sp = None, 0.0, 0.0
    else:
        heading = mag.heading(fusion.pitch, fusion.roll)
        heading_error = wrap_deg_error(heading_setpoint, heading)
        yaw_rate_sp = max(
            -tuning.MAX_YAW_RATE_DPS,
            min(tuning.MAX_YAW_RATE_DPS, tuning.HEADING_KP * heading_error),
        )

    roll_cmd = rate_pid["roll"].update(roll_rate_sp, gyro_x, dt)
    pitch_cmd = rate_pid["pitch"].update(pitch_rate_sp, gyro_y, dt)
    yaw_cmd = rate_pid["yaw"].update(yaw_rate_sp, gyro_z, dt)

    return roll_deg, pitch_deg, heading, heading_error, roll_cmd, pitch_cmd, yaw_cmd
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

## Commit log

2026-09-04 Initial commit: flight controller scaffold and bench test suite
    Sensor drivers, control maths, and a component-by-component bench
    procedure for a coreless quadcopter on a Raspberry Pi Pico 2 W.
    Hardware layer:
    - MotorBank over two DRV8833s, with GP15 driving SLP on both as a
    hardware disarm that a software bug cannot override
    - MPU6050, HMC5883L (auto-detecting the QMC5883L clone), NEO-6M GPS
    Control maths:
    - complementary filter, PID with anti-windup and derivative-on-
    measurement, X-quad mixer that desaturates rather than clips
    testing/ holds one folder per component, each with a wiring table in
    physical pin numbers and a runnable script. src/config.py is the single
    source of truth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
    [config.py, gps.py, hmc5883l.py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]
2026-09-04 ci: bump actions to current majors
    Clears the Node 20 deprecation warning on every job. checkout v4 ->
    v7, setup-python v5 -> v7, upload-artifact v4 -> v7, gh-release
    v2 -> v3.
2026-09-04 ci: fix link check always passing, and tag resolution on dispatch
    The docs job piped find output into a while loop, putting the inner
    loop in a subshell - so fail=1 never reached the parent and the job
    passed even with broken links. Collect hits into a file instead.
    Verified it now fails on a deliberately broken link.
    release.yml read GITHUB_REF_NAME first, which on workflow_dispatch is
    the branch name, so the tag input was ignored. Prefer the input. Also
    stop copying src/__init__.py to the board root, where it means nothing.
2026-09-04 ci: keep __pycache__ out of the release bundle
    The compile-check step runs compileall on src/, which leaves CPython
    __pycache__ directories behind, and the copy then swept them into the
    zip - ~35 KB of .pyc in the wrong bytecode format for MicroPython,
    wasting the Pico's flash. Clear them after compiling and again after
    copying.
    Caught by dispatching the workflow rather than reading it.
2026-09-04 Pulse the onboard LED for as long as any script runs
    A liveness failsafe: if the LED is pulsing, the board is powered and
    its scheduler is running. If it stops and restarts, the board reset -
    which on this airframe means a brownout.
    drivers/heartbeat.py runs on a soft timer, so it keeps beating through
    blocking calls: the six-second multimeter pauses in the DRV8833 test,
    the minutes of wait_for_fix() in the GPS test. Scripts do not have to
    call anything from inside their loops.
    Long on / short off, so it reads as a glow rather than a blink while
    still visibly beating. The Pico 2 W's LED hangs off the CYW43 chip and
    cannot be PWM'd, so a real fade was not an option. "blink" and "solid"
    mode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
    [heartbeat.py, main.py, test_drv8833.py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]
2026-09-04 Explain the missing-library ImportError, and give a way to fix it
    Running any bench script without uploading the library first failed with
    a bare:
    ImportError: no module named 'config'
    which says nothing about the actual cause. The imports resolve against
    the BOARD's filesystem, not the computer's, so opening a file in Thonny
    and pressing Run is not enough - the modules have to be on the Pico.
    testing/README.md mentioned this in one sentence, no component README
    mentioned it at all, and there was no tooling to do it. That was a real
    gap, not a user error.
    - tools/upload.sh copies config.py, main.py, drivers/ and flight/ to the
    board root over mpremote. --list shows what is there, -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
    [test_drv8833.py, test_gy521_imu.py, test_gy_gps6mv2.py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]
2026-09-04 Stop uploading main.py to the board - it hijacks every test run
    Root cause of "test_gy521_imu.py just prints MPY: soft reboot twice and
    nothing else": tools/upload.sh was copying main.py to the board root.
    MicroPython auto-runs a file named main.py on every boot AND every
    soft-reboot, and Thonny's Run button always soft-reboots the board
    first. With main.py resident, every Run re-entered it instead of the
    test script the user actually opened - and main.py's sensor bring-up
    blocks forever, both in the no-IMU path and in the live-streaming loop,
    so it never returned control. The test script never got a chance to
    execute; the symptom is total silence except the reboot banner.
    upload.sh no long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
2026-09-04 Stop README step 4 from silently reintroducing the main.py hijack
    Step 4 ("Run it") told the reader to copy all of src/ to the board root
    - including main.py - with no warning. Anyone who did the bench tests
    in step 3 and then followed step 4 would have main.py sitting on their
    board afterwards, hijacking every subsequent test run exactly the way
    PR #3 fixed for upload.sh. The doc and the tool disagreed with each
    other.
    Now explicit: main.py goes on deliberately and separately, with a
    one-line mpremote command instead of a vague "copy the contents", and a
    matching warning to remove it before going back to bench testing.
2026-09-04 Print error messages before raise SystemExit(), not inside it
    Root cause of the GY-521 test showing two "MPY: soft reboot" lines and
    nothing else: MicroPython/Thonny treats an uncaught SystemExit as a
    clean exit request, not an error - its message argument is silently
    discarded rather than displayed. Every guard in these scripts relied
    entirely on that argument to tell the user what went wrong, so the
    message never reached the screen. The board was correctly running the
    script; the error-reporting mechanism itself was silent by construction.
    Confirmed empirically: os.listdir() on the board returned [], so the
    config-not-uploaded ImportError path was firing exactly as designed -
    it just neve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
    [test_drv8833.py, test_gy521_imu.py, test_gy_gps6mv2.py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]
2026-09-04 Restore branch protection on main - PR-only, human merge
    Direct push to main is rejected by GitHub, verified. enforce_admins is
    on, so this applies to Claude too, not just anyone else with push
    access. required_approving_review_count is 0 deliberately: a solo
    owner can't approve their own PR, so requiring 1 would make every PR
    permanently unmergeable - the PR requirement itself is the actual gate,
    not the approval count.
    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
2026-09-05 Add firmware/: attitude-hold flight controller
    Cascaded PID (rate loop off the gyro, angle loop off the complementary
    filter, heading-hold off the compass) driving the existing mixer, built
    entirely on drivers and control maths already validated in src/ and
    testing/ - nothing new at the hardware layer.
    Explicitly NOT a hover controller: nothing on this airframe measures
    altitude (GPS is 1-10m/1-5Hz, useless for this) or position, so it
    self-levels and holds a heading at a fixed throttle and will still
    climb/sink/drift. Documented plainly in firmware/README.md rather than
    pretending otherwise. True hover needs a barometer at minimum; the code
    leaves a seam for one but doesn't fake having it.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
    [flight_controller.py, test_angles.py, tuning.py]
2026-09-06 Add full consolidated wiring info to firmware/README.md
2026-09-30 Add firmware/lift.py lift test and extend testing for both drivers
    lift.py ramps to a set throttle, holds, and ramps down with the cascaded
    attitude loop active. Gains are inline so edits in Thonny take effect
    without re-uploading tuning.py. Supports STANDARD wiring (motor across
    OUT1+OUT2 / OUT3+OUT4) and SHARED wiring (two motors to GND on one bridge,
    interleaved PWM). Frees a stuck I2C bus, rides out brief IMU read
    failures, and disarms on a dead or frozen IMU.
    Also: 02_drv8833 now walks all four channels on both boards, and adds
    the 08 full-stack dry run.
    [lift.py, test_drv8833.py]
2026-10-01 lift.py: hold-until-Stop mode and bench settings for a 1S build without caps
    HOLD_S = None now holds LIFT_THROTTLE until Thonny's Stop (Ctrl-C), which
    lands in the existing KeyboardInterrupt handler and disarms in finally.
    The banner says which mode is active.
    Bench defaults changed to what ran clean on 2026-10-01: SHARED wiring,
    LIFT_THROTTLE 0.40, IDLE 0.30. The higher idle floor keeps every motor
    above coreless start-up duty, so the levelling correction can no longer
    leave one motor stalled while its partner spins.
    [lift.py]
2026-10-01 lift.py: raise lift throttle to 0.50, keep integrators off on the ground
    LIFT_THROTTLE 0.40 -> 0.50 for a first lift attempt (25% duty in SHARED).
    I_ENABLE_THROTTLE 0.35 -> 0.55 so it sits above the test throttle. The
    2026-10-01 run at 0.40 showed the pitch integrator winding up on the ground
    (rear motors 0.44 -> 0.57 over ~9 s while front motors pinned at the 0.30
    idle floor); that stored correction would lurch the quad on liftoff.
    [lift.py]
2026-10-01 Add KiCad schematic and protoboard wiring diagram
    hardware/ holds two KiCad 9 projects that share one sym-lib-table:
    - pico-drone.kicad_sch: full schematic. Power, Pico 2 W, both DRV8833s
    with motors, IMU, compass and GPS, plus build notes and a wiring
    table. PDF alongside.
    - pico-drone-wiring.kicad_sch: protoboard wiring diagram. Every
    connection is a coloured wire from pin to pin, each board drawn in
    its physical header order, with a colour legend and a motor-position
    map. PDF alongside.
    Both are drawn as STANDARD motor wiring (IN2/IN4 to GND) with the
    470 uF caps marked "not fitted yet". KiCad's exported netlist for each
    sheet matches the pin map in src/config.py and firmware/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
    [pico-drone-wiring.kicad_sch, pico-drone.kicad_sch]
2026-10-07 Add 3D-printed frame: Onshape FeatureScript, STLs and print guide
    hardware/frame/ holds a parametric quad frame generated by an Onshape
    FeatureScript feature (pico_drone_frame.fs), plus print-oriented STLs:
    - frame (8.7 g PLA): one-piece deck + tapered T-section arms + split-clamp
    motor pods + Warren-truss battery bay for the 852040 pack; pins-down
    headers drop through deck slots into a 10 mm wiring bay
    - GPS + compass mast (2.7 g), bolt-on with 2x M2 self-tappers
    - tolerance coupon: 5 motor-bore allowances and 3 header-slot widths
    Every edge is filleted, prints with no supports, and all parts were
    clearance-checked in Onshape against dummies of every board, the battery,
    motors and pro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
    [pico_drone_frame.stl, pico_drone_gps_mast.stl, pico_drone_tolerance_coupon.stl]
2026-10-09 Bench setup on HW-131 supply, drop the compass, lift.py bench fixes
    Wiring docs now match the bench as built: Pico on laptop USB, motors on an
    HW-131 breadboard supply (5 V rail -> both DRV VM), one wire joining the
    grounds, GY-521 on 3V3 OUT, GPS on VBUS (pin 40, gets a lock there). STANDARD
    motor wiring throughout.
    HMC5883L removed from the build: on the shared I2C bus it knocked the IMU
    offline whenever the motors ran. flight_controller.py now runs without a
    compass (yaw rate-hold only, heading drifts).
    lift.py: WIRING STANDARD, hold until Stop, solid LED so Stop always lands in
    the main loop, staggered one-motor-at-a-time spin-up, IDLE 0.40 so no motor
    sits stalled, LEVELLING switch wi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
    [flight_controller.py, imu_motor_check.py, lift.py]
2026-10-09 Docs: make the breadboard-rail grounding rule explicit
    With the HW-131 plugged into the breadboard's power rails, every rail is motor
    ground. A sensor grounded on a rail (the GPS, and most likely the compass
    before it) shares the motor return path, and the IMU drops off I2C the moment
    the motors spin. Moving the GPS ground straight to Pico pin 3 fixed it.
    The rule - sensor GND straight to Pico pins, exactly one wire between Pico GND
    and the HW-131 GND rail, HW-131 on a wall charger - is now stated in
    docs/power.md (with the symptom and a multimeter check), linked from the
    pinout, firmware README and GPS README, and named first in lift.py's
    troubleshooting list and its "IMU stopped answering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
    [lift.py]
2026-10-09 lift.py: show GPS lock quality and coordinates
    A gps: line before the ARM prompt and once a second during the run: fix
    type, satellites, HDOP with a rating, lat/lon and altitude. Display only -
    no data or no fix never stops the run. SHOW_GPS turns it off, and a board
    without drivers/gps.py still runs.
    [lift.py]
2026-10-09 Coreless motor test: ramp to full throttle (scaled to MAX_DUTY)
2026-10-10 lift.py: default LIFT_THROTTLE to full (1.0)
    Throttle 1.0 is still scaled to config.MAX_DUTY (70% duty), so the
    DRV8833 cap is unchanged.
2026-10-27 RL M0: pure-Python policy runner and Pico speed benchmark
    flight/policy.py runs a tanh MLP with no numpy, sharing the observation
    layout the simulator will train on. firmware/bench_policy.py times 2x12..2x32
    networks plus the rest of the loop so the sim can train the largest size the
    Pico keeps at 100 Hz. Motors stay asleep throughout.
2026-10-27 Fix yaw sign: mixer +yaw now matches gyro z (counter-clockwise)
    The mixer raised the CCW pair for +yaw, which turns the nose right (gyro z
    negative), while every yaw rate loop feeds gyro z straight into its PID - so
    the yaw loop was positive feedback. Never visible with props off. The new
    MuJoCo sim (physics independent of the mixer) showed lift.py's PID spinning
    the drone to ~1000 deg/s; with the column flipped yaw holds within a few deg/s.
    Compass heading grows clockwise, so flight_controller's heading hold now
    negates its yaw-rate setpoint (inactive while the compass is removed).
2026-10-27 RL M1: MuJoCo model of the pico-drone with a board-faithful loop
    sim/ is its own uv project (Python 3.12, MuJoCo, SB3, CPU torch). The drone
    is a free body with coreless motor lag/curve/sag, prop drag torque, a
    weight-relief force standing in for the balloon, and an MPU6050 model (noise,
    vibration, bias, DLPF, mounting error). Everything is randomized per episode
    from drone_params.json. HoverEnv runs the board's own fusion, mixer and
    policy observation code each step. watch.py opens a viewer (kick, move CoM).
    Policy output layer is now linear + clip to match SB3's deterministic action.
2026-10-27 Sim: build the drone from the Onshape model's real parts
    airframe.py ports the fit-check dummies and layout from
    hardware/frame/pico_drone_frame.fs (Pico, both DRV8833s, GY-521, battery,
    motors, props, GPS + antenna on the mast), each with its real mass, and loads
    the frame and mast STLs (rotated from print to flight orientation: verified
    from the battery bay's front wall and the mast leg offset). MuJoCo computes
    mass/CoM/inertia from them: 64.4 g, matching Onshape's all-up figure. Wires
    are a randomized extra mass and CoM shift. The IMU site sits where the GY-521
    does. Integrator switched to Euler: implicitfast blew up on this light body.
2026-10-27 Sim: seed the attitude filter properly on mid-air starts; add PPO trainer
    Mid-air resets seeded the complementary filter from a single accelerometer
    read taken before any thrust was applied - the drone was in free fall, the
    accelerometer read ~0 g, and atan2 of noise put the estimate up to 70 deg
    off. Every controller then spent the first second chasing a phantom tilt:
    lift.py's PID tipped some drones over, and the baseline crash rate (8/60)
    was mostly this. Now a mid-air start seeds the filter with the true
    attitude through the IMU mount (+-1 deg), as if it had been tracking since
    take-off, and Drone.reset applies motor and relief forces before computing
    sensors. Floor starts are unchanged.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
2026-10-27 Autotune: in-flight system identification + gain scaling, checked in the sim
    src/flight/autotune.py - the PX4/QGC-style autotune, pure Python so the
    board and the simulator run the same file. Flies on the current gains,
    excites roll, pitch, yaw in turn with a pseudo-random square wave, and fits
    dw[k] = a dw[k-1] + b0 u[k-1] + b1 u[k-2] + b2 u[k-3] + c
    per axis by recursive least squares -> authority K, motor lag tau, dead
    time, and the trim that cancels a CoM offset (wires).
    What the simulator forced (sim/autotune_sim.py):
    - three input taps, not one: a single tap read K 35-45 % off;
    - the same 15 Hz prefilter on input and output: gyro noise otherwise
    dragged the lag estimate to zero;
    -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
2026-10-27 Sim: watch PPO learn live in a MuJoCo window; README for training and autotune
    watch_training.py trains a throwaway policy in its own process and flies the
    current one on a fresh randomized drone each episode, with the randomization
    drawn in: CoM marker, balloon-relief arrow, per-motor thrust arrows, the
    drone's parameters and a learning curve on screen.
    Two viewer traps found on the way: set_texts/set_figures take the viewer lock
    themselves (calling them under viewer.lock() froze the window), and MuJoCo's
    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
2026-10-27 RL: export the trained policy for the board (2x32, 6M steps)
    sim/export_policy.py pulls the actor (mlp_extractor.policy_net + action_net)
    out of an SB3 zip, checks the pure-Python flight/policy.py copy against torch
    on real episodes (max diff 2.6e-8), flies it against lift.py's PID on 60
    randomized drones, and writes src/flight/policy_weights.py.
    Result for runs/ppo_20261027_124351/best.zip: PPO crashed 1/60, median RMS
    tilt 3.5 deg; lift.py's PID crashed 1/60, 2.8 deg. In the sim the policy
    matches the PID but does not beat it yet.
2026-10-27 sim: scene hooks for a keyboard-flown sim (extra MJCF, force hook, relief toggle, attitude/yaw setpoints)
    Defaults are unchanged, so training and the checks see the same drone.
    Groundwork for sim/fly.py.
2026-10-27 sim: fly.py - fly the drone with the keyboard in a room
    Trained policy (or lift.py PID, C to switch) does the levelling; keys move
    its tilt/yaw/throttle targets. Adds what the real room has: 5 helium
    balloons on string tendons as their own bodies (drag, added mass, collisions),
    walls and furniture, wind gusts, a draining 1S battery, ground effect.
    Sim-only altitude hold and loiter helpers, live attitude-vs-target graph.
    --check: scripted 40 s flight, policy vs PID, balloons vs lumped relief.
2026-10-27 sim: autotune a CoM-shifted drone and fly the result; tie-the-strings-over-the-CoM finding
    autotune_sim.py: --com FWD LEFT, --extreme NAME, --random pick the drone to
    tune (was nominal only); the windowed run now prints lift.py vs autotuned too.
    fly.py: --gains autotune (PID gains + trim from runs/autotune_gains.json),
    --com, T / --tie-at-com moves the string knot over the real CoM, softer sticks
    (12 deg, 45 deg/s slew, 60 dps yaw).
    With the CoM 5 mm off-centre a centre knot hangs the frame 12-20 deg and the
    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
2026-10-27 Autotune session: the PX4 flow around the identification
    src/flight/autotune_session.py: start from the ground station, wait for a
    steady hover, excite roll/pitch(/yaw) with a progress bar and status texts,
    abort on tilt > 25 deg, stick input, link loss or landing (old gains keep
    flying), then accept now (fly + 3 s wobble check, auto-revert - PX4's
    MC_AT_APPLY=2), accept after landing (MC_AT_APPLY=1) or reject.
    Autotune can now skip yaw. 12 tests on a synthetic 3-axis drone.
2026-10-27 SITL vehicle + ground-station link for the PX4-style autotune
    - src/drivers/gcs_link.py: JSON-over-UDP link (MAVLink-style ports, vehicle
    replies to the last sender), non-blocking, MicroPython-safe
    - src/flight/ground_station.py: telemetry 10 Hz, status texts, acks, result
    and gains messages; commands at_start/at_abort/accept/reject/get_gains/disarm,
    deliberately no remote arm
    - sim/sitl.py: fly.py's drone + lift.py PID + autotune session + link on UDP
    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
2026-10-27 Ground station: QGC-style autotune page (gcs/gcs.py)
    tkinter, stdlib only. Link status + DISARM (software, not a kill switch; no
    remote arm), artificial horizon, motor bars, gyro strip chart, gains flying
    now; autotune amplitude (MC_AT_SYSID_AMP) + include yaw, Start/Abort,
    per-axis progress, result table, predicted before/after step response
    (src/flight/step_response.py: the fitted model closed with the board's PID),
    Accept now/after landing, Reject, status log.
2026-10-27 Board side of the PX4-style autotune: firmware/autotune.py + saved gains
    - firmware/autotune.py: Thonny script, WiFi AP/STA up before the ARM/DRY
    prompt, fixed 100 Hz loop (the reference drone's rate), ground-station link
    + autotune session; refuses to tune in DRY, while ramping, or above
    MAX_TUNE_THROTTLE (no headroom - add balloon relief); SLP low at start and
    in finally; accepted gains written to /gains.json only after disarm
    (PX4 apply-on-disarm for 'landing'). UNTESTED ON HARDWARE.
    - src/flight/gains_file.py: load never fails (defaults + reason), sanity
    limits, atomic save via temp + rename; used by sitl.py and the board
    - lift.py: USE_SAVED_GAINS, prints which gains/trim ar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
2026-10-27 Autotune docs: DRY sign check, /usr/bin/python3 for the GCS, link wording
    - DRY step checks signs numerically: right side down = roll +, nose down =
    pitch + (the mixer's convention); stop if either is reversed
    - GCS commands use /usr/bin/python3 (miniforge / uv Tk lack font rendering)
    - README / firmware README: there is now a WiFi ground station that can
    disarm in software, still no RC link and no physical kill switch
    - firmware console: no doubled 'autotune: Autotune:' prefix; messages queued
    at disarm (e.g. 'landed - new gains applied') are printed
